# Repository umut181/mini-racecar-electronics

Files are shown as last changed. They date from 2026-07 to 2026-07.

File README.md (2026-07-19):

# Mini Racecar Electronics

A custom electronics board for a **2WD, IR-controlled differential-drive robot vehicle**, designed in **KiCad**.

---

## Overview

| | |
|---|---|
| **Form factor** | < 100 mm × 100 mm |
| **Fabrication** | 2-layer rigid FR-4, via Robotistan PCB Service |
| **Battery input** | 2S–6S LiPo (4.5 V – 40 V input range) |
| **Logic compatibility** | Any 5 V-based microcontroller |
| **Motor support** | Low-reduction 3–6 V TT motors, 150 mA (no load) – 1.5 A (stall) |

---

## Power & Drive Architecture

The board combines a **buck-style power stage** (inductor + Schottky + electrolytic caps) to step the LiPo input down for logic rails, and a **dual full H-bridge** built from discrete `IRF540N` MOSFETs (driven via `IR2104` half-bridge drivers) to independently control two DC motors for differential steering. IR receiver pins bring in the remote-control signal.

---

## Bill of Materials

### Power Stage

| Ref | Value | Notes |
|---|---|---|
| L1 | 33 µH | Radial inductor, Fastron 07HCP |
| D1 | 5 A / 100 V Schottky | Buck rectifier |
| Q — power switching | 8× IRF540N | TO-220, vertical |
| IC — gate drivers | 4× IR2104 | DIP-8, half-bridge driver |

### Capacitors

| Ref | Value | Package |
|---|---|---|
| C1 | 100 µF / 16 V | Electrolytic |
| C2 | 220 µF / 16 V | Electrolytic |
| C9 | 470 µF / 16 V | Electrolytic |
| C12 | 470 µF / 16 V | Electrolytic |
| C7, C13 | 1 µF | SMD 1206 |
| C8, C15 | 10 µF | SMD 1206 |
| C3, C4, C11, C14 | 0.47 µF | SMD 0805 |
| C5, C6, C10, C16 | 0.1 µF | SMD 0805 |

### Diodes

| Ref | Value | Package |
|---|---|---|
| D1 | 5 A / 100 V Schottky | — |
| D2, D3, D4, D5, D6, D10, D11, D12 | 1N4148 | THT DO-35, 7.62 mm |
| D7, D8, D9, D13 | MURS260 | SMD, SMB |

### MOSFETs & Gate Drive

| Ref | Part | Package |
|---|---|---|
| Q1–Q8 | IRF540N | TO-220-3, vertical |
| IR2104 ×4 | Half-bridge driver | DIP-8 |

### Resistors

| Ref | Value (Ω) | Package |
|---|---|---|
| R1, R2, R3, R4, R6, R7, R9, R10 | 10 | SMD 0805 |
| R5, R8 | 0.1 (current sense) | SMD 0805 |

### Connectors

| Ref | Type | Footprint |
|---|---|---|
| Load1, Load2, Input | 2-pin terminal block | MaiXu MX126-5.0-02P, 5.00 mm pitch |
| IR_pins | 3-pin header | 2.54 mm pin header, vertical |
| IR_pins1 | Custom | — |

---

## Tooling

Designed entirely in **KiCad**.

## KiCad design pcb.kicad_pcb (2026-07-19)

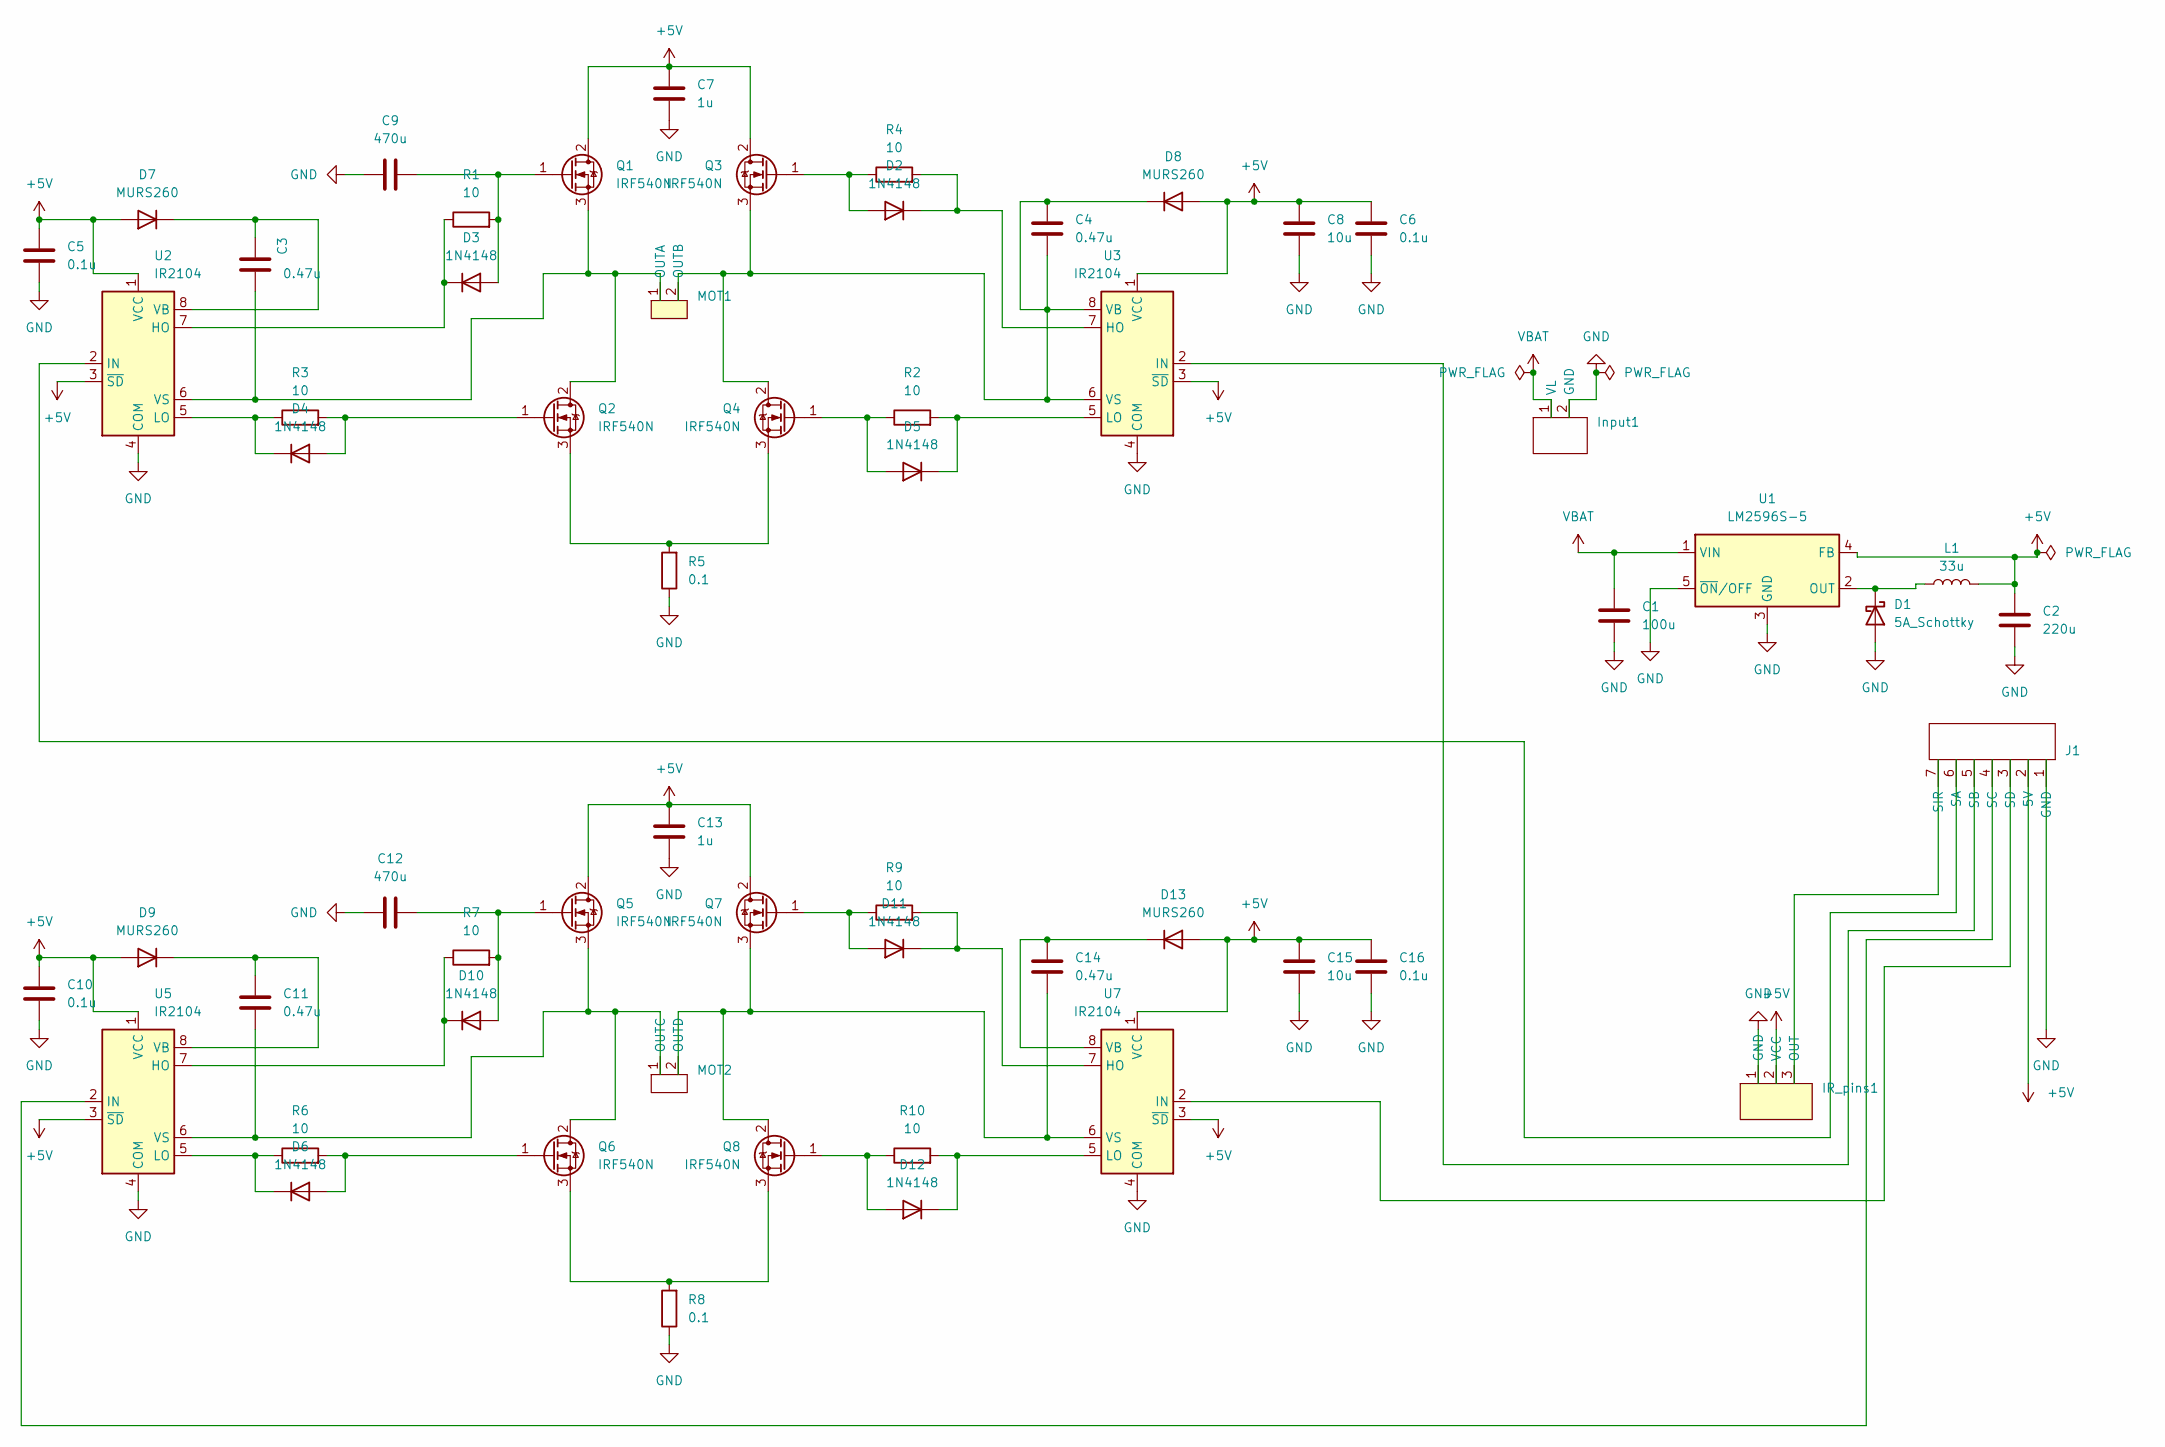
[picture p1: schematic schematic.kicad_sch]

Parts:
C1: 100u; CP_Axial_L11.0mm_D5.0mm_P18.00mm_Horizontal
C2: 220u; CP_Axial_L11.0mm_D6.0mm_P18.00mm_Horizontal
C3, C4, C11, C14: 0.47u; C_0805_2012Metric_Pad1.18x1.45mm_HandSolder
C5, C6, C10, C16: 0.1u; C_0805_2012Metric_Pad1.18x1.45mm_HandSolder
C7, C13: 1u; C_1206_3216Metric_Pad1.33x1.80mm_HandSolder
C8, C15: 10u; C_1206_3216Metric_Pad1.33x1.80mm_HandSolder
C9, C12: 470u; C_Axial_L12.0mm_D8.5mm_P15.00mm_Horizontal
D1: 5A_Schottky; D_DO-201AD_P5.08mm_Vertical_AnodeUp
D2, D3, D4, D5, D6, D10, D11, D12: 1N4148; D_DO-35_SOD27_P7.62mm_Horizontal
D7, D8, D9, D13: MURS260; D_SMB_Handsoldering
IR_pins1: PinSocket_1x03_P2.54mm_Vertical
Input1: TerminalBlock_MaiXu_MX126-5.0-02P_1x02_P5.00mm
J1: PinHeader_1x07_P2.54mm_Vertical
L1: 33u; L_Radial_D7.8mm_P5.00mm_Fastron_07HCP
MOT1, MOT2: TerminalBlock_MaiXu_MX126-5.0-02P_1x02_P5.00mm
Q1, Q2, Q3, Q4, Q5, Q6, Q7, Q8: IRF540N; TO-220-3_Vertical
R1, R2, R3, R4, R6, R7, R9, R10: 10; R_0805_2012Metric_Pad1.20x1.40mm_HandSolder
R5, R8: 0.1; R_0805_2012Metric_Pad1.20x1.40mm_HandSolder
U1: LM2596S-5; TO-263-5_TabPin3
U2, U3, U5, U7: IR2104; DIP-8_W7.62mm

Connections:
+5V: C2.1, C5.1, C6.1, C7.1, C8.1, C10.1, C13.1, C15.1, C16.1, D7.2 (A), D8.2 (A), D9.2 (A), D13.2 (A), IR_pins1.2 (VCC), J1.2 (5V), L1.2, Q1.2 (D), Q3.2 (D), Q5.2 (D), Q7.2 (D), U1.4 (FB), U2.1 (VCC), U2.3 (~SD), U3.1 (VCC), U3.3 (~SD), U5.1 (VCC), U5.3 (~SD), U7.1 (VCC), U7.3 (~SD)
GND: C1.2, C2.2, C5.2, C6.2, C7.2, C8.2, C9.1, C10.2, C12.1, C13.2, C15.2, C16.2, D1.2 (A), IR_pins1.1 (GND), Input1.2 (GND), J1.1 (GND), R5.1, R8.1, U1.3 (GND), U1.5 (~ON/OFF), U2.4 (COM), U3.4 (COM), U5.4 (COM), U7.4 (COM)
unnamed: D1.1 (K), L1.1, U1.2 (OUT)
unnamed: D2.2 (A), Q3.1 (G), R4.1
unnamed: D2.1 (K), R4.2, U3.7 (HO)
unnamed: C9.2, D3.2 (A), Q1.1 (G), R1.2
unnamed: D3.1 (K), R1.1, U2.7 (HO)
unnamed: D4.2 (A), Q2.1 (G), R3.2
unnamed: D4.1 (K), R3.1, U2.5 (LO)
unnamed: D5.2 (A), Q4.1 (G), R2.1
unnamed: D5.1 (K), R2.2, U3.5 (LO)
unnamed: D6.2 (A), Q6.1 (G), R6.2
unnamed: D6.1 (K), R6.1, U5.5 (LO)
unnamed: C3.1, D7.1 (K), U2.8 (VB)
unnamed: C4.1, C4.2, D8.1 (K), MOT1.2 (OUTB), Q3.3 (S), Q4.2 (D), U3.6 (VS), U3.8 (VB)
unnamed: C11.1, D9.1 (K), U5.8 (VB)
unnamed: C12.2, D10.2 (A), Q5.1 (G), R7.2
unnamed: D10.1 (K), R7.1, U5.7 (HO)
unnamed: D11.2 (A), Q7.1 (G), R9.1
unnamed: D11.1 (K), R9.2, U7.7 (HO)
unnamed: D12.2 (A), Q8.1 (G), R10.1
unnamed: D12.1 (K), R10.2, U7.5 (LO)
unnamed: C14.1, D13.1 (K), U7.8 (VB)
unnamed: IR_pins1.3 (OUT), J1.7 (SIR)
unnamed: J1.6 (SA), U2.2 (IN)
unnamed: J1.5 (SB), U3.2 (IN)
unnamed: J1.4 (SC), U5.2 (IN)
unnamed: J1.3 (SD), U7.2 (IN)
unnamed: C3.2, MOT1.1 (OUTA), Q1.3 (S), Q2.2 (D), U2.6 (VS)
unnamed: C11.2, MOT2.1 (OUTC), Q5.3 (S), Q6.2 (D), U5.6 (VS)
unnamed: C14.2, MOT2.2 (OUTD), Q7.3 (S), Q8.2 (D), U7.6 (VS)
unnamed: Q2.3 (S), Q4.3 (S), R5.2
unnamed: Q6.3 (S), Q8.3 (S), R8.2
VBAT: C1.1, Input1.1 (VL), U1.1 (VIN)

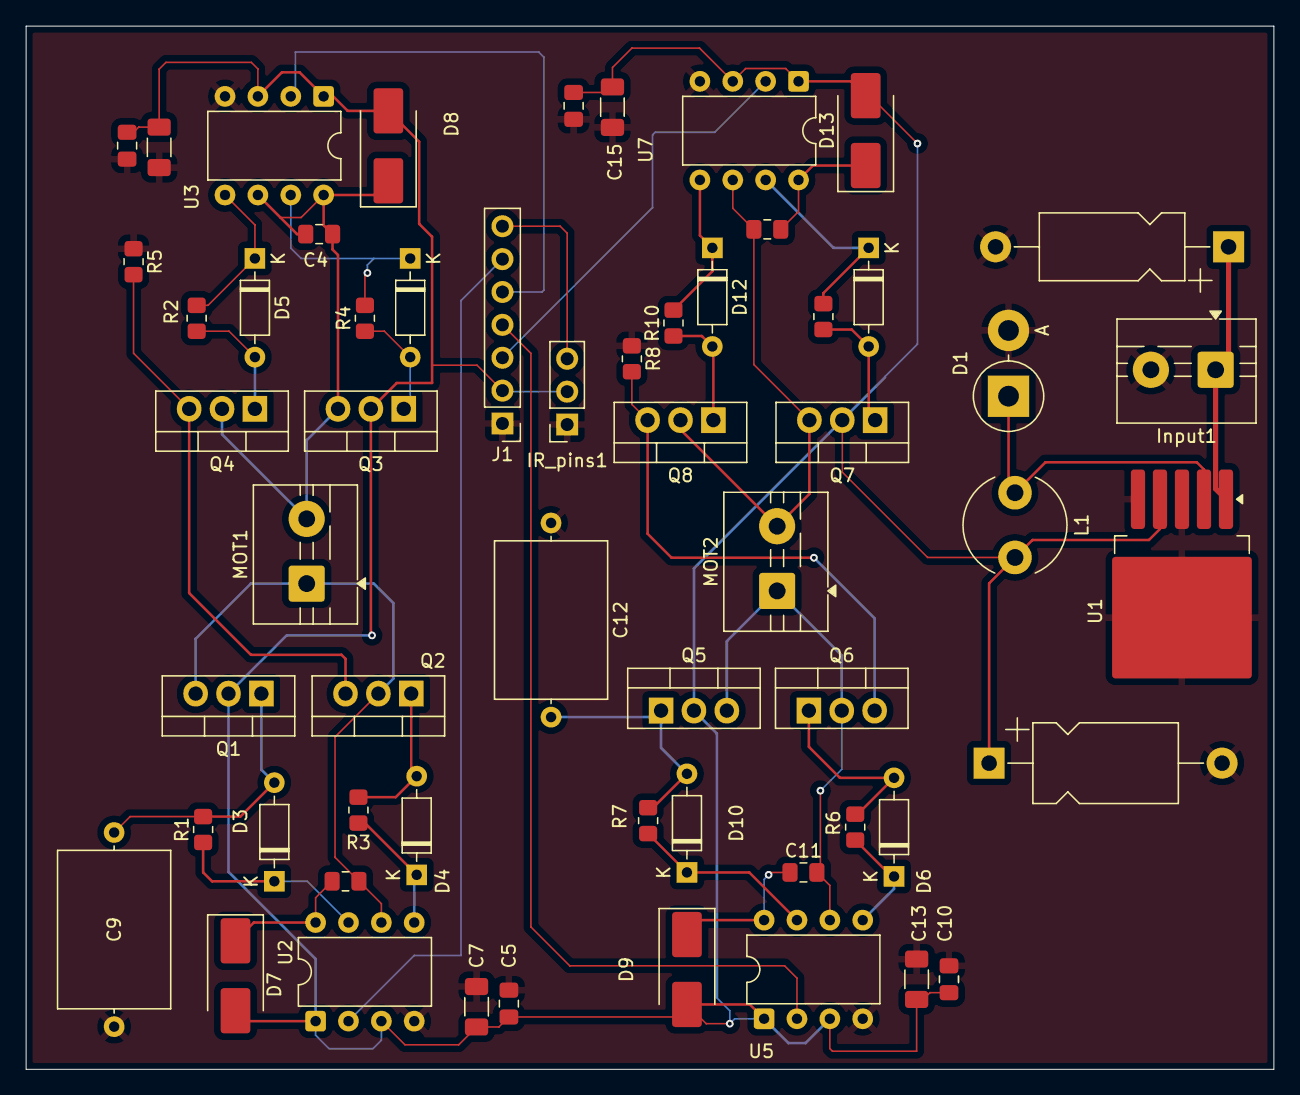
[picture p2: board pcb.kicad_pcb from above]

Board: 4 copper layers, 96.4 x 80.6 mm, 58 parts (0 on the bottom side), 34 nets.

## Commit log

2026-07-19 View the PCB design.
    [pcb.kicad_pcb]
2026-07-19 View the schematic.
    [schematic.kicad_sch]
